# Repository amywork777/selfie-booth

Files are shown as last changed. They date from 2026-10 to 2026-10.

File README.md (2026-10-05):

# Selfie booth

An iPad selfie booth that prints on a 4x6 thermal label printer. Guests pick how many photos, pick a
pattern, add a caption (or a doodle), pose, and walk away with a print.

**Not technical? Read [START HERE](START%20HERE.md)** and double-click `Start Booth` on a Mac.

```
iPad (Safari) ··Wi-Fi··> a Mac or Raspberry Pi running server.py ──USB──> thermal printer
```

The iPad can't drive a USB printer itself, so a small computer sits in the middle. The iPad page does
everything people see: camera, countdown, patterns, caption, and turning the photo into printer dots.
The server only passes the finished label to the printer over USB. No printer driver is needed.

## What you need

- An iPad (any recent one with a front camera) on the same Wi-Fi as the computer.
- A Mac (or a Raspberry Pi, see below).
- A 4x6 direct thermal label printer that understands **TSPL** commands. Built and tested with a
  **Rollo X1038** (the USB model). Other TSPL printers should work after changing the USB IDs (below).
- 4x6 direct thermal labels.

## Run it on a Mac

Double-click **Start Booth** (`Start Booth.command`). The first run makes a Python environment and
installs `requirements.txt` (pyusb, Pillow, and libusb-package, which bundles libusb so no Homebrew is
needed), and it keeps the Mac awake while the booth runs. By hand, the same thing is:

```
python3 -m venv .venv && .venv/bin/python -m pip install -r requirements.txt
caffeinate -i .venv/bin/python server.py
```

Every time:

1. Plug the printer into the Mac and switch it on.
2. Double-click **Start Booth** and leave its window open.
3. On the iPad (same Wi-Fi as the Mac), open **https://selfie-booth.local:8443**. Add it to the Home
   Screen (Share, Add to Home Screen) for one-tap opening, and turn on Guided Access (Settings,
   Accessibility) to lock the iPad to the booth.

The address is the same on any Wi-Fi: the server announces `selfie-booth.local` on whatever network
it's on.

### First time on an iPad: trust the booth (once)

The booth uses https because Safari only allows the live camera on https. The server makes its own
small certificate authority (kept in `certs/`, never committed). Each iPad trusts it once:

1. On the iPad, open **http://selfie-booth.local:8000** and tap **Download the booth certificate**, then
   Allow.
2. Settings, **Profile Downloaded**, Install.
3. Settings, General, About, **Certificate Trust Settings**, turn on **Selfie Booth**.

After that the booth opens with no warning, even after the Mac changes networks. If you delete the
`certs/` folder, a new authority is made and iPads need to do this again.

If `selfie-booth.local` doesn't load, the server also prints the Mac's own `.local` name and its IP
address to try instead. Also check the Mac didn't pop up an "allow incoming connections" box for Python.

## Using the booth

Guests go through:

1. **How many photos:** 1 photo, 2 poses, 2 x 2, or twin strips (4 poses printed twice, with a cut line).
2. **Pick a pattern:** Plain, Hearts, Polka dot, Gingham, Doodle, Daisy chain.
3. **Caption:** type a caption. On Plain they can also doodle on the label with a finger.
4. **Smile:** a 3-2-1 countdown per pose, then it prints on its own.

**Settings** (small button, top right, on steps 1 and 2) is for the host:

- **Captions:** *Guests write their own*, or *Same for everyone* with one event caption. With the same
  caption for everyone, guests skip step 3 (except on Plain, where it becomes "Doodle on it").
- **Date** on or off, **Sound** on or off.

To see every pattern and photo count at once: https://selfie-booth.local:8443/frames.html

## Files

| File | Does |
| --- | --- |
| `server.py` | Serves the iPad page over https, `POST /print` (PNG in, prints it), `GET /status`, `POST /log` |
| `printer.py` | Finds the printer over USB and wraps an image in TSPL (808 x 1218 dots, 1-bit) |
| `static/app.js` | The booth: steps, camera, countdown, doodling, printing |
| `static/label.js` | Draws the label: photo counts, patterns, stickers, caption |
| `static/dots.js` | Contrast and Floyd-Steinberg dithering (tested: `npm test`) |
| `static/frames.html` | Every pattern and count side by side |
| `print_photo.py` | Print any photo from Terminal: `.venv/bin/python print_photo.py photo.jpg` |

## A different printer

In `printer.py`:

- `VID, PID`: your printer's USB IDs. On a Mac, find them with `system_profiler SPUSBDataType`.
- `PAPERS`: the paper sizes the booth offers (also in `static/label.js`). Labels use a gap, continuous rolls don't.
- `INVERT`: flip it if prints come out as a negative.
- Label widths are rounded down to a multiple of 8 dots (4 in is 808, not 812), or every row skews.

## Run it on a Raspberry Pi instead of a Mac (not tested yet)

Needs a Raspberry Pi Zero 2 W, a microSD card (8 GB+), a micro-USB OTG adapter for the printer cable,
and a micro-USB power supply.

1. Flash the card with Raspberry Pi Imager: Raspberry Pi OS Lite (64-bit). In its settings set a
   hostname (e.g. `booth`), your Wi-Fi, and turn on SSH.
2. Printer cable into the OTG adapter, into the Pi's port labelled **USB** (the middle one). Power into
   **PWR IN** (the corner one).
3. Copy the folder over (without `.venv` and `certs`), then on the Pi:
   `sudo apt install -y python3-venv libusb-1.0-0 openssl`, the same venv and `requirements.txt` install,
   and `sudo .venv/bin/python server.py` (raw USB needs permission).
4. On the iPad, open https://selfie-booth.local:8443 as before (the Pi announces the same name through
   Avahi, if `avahi-utils` is installed). The Pi makes its own certificate authority, so each iPad trusts it
   once, from http://selfie-booth.local:8000.

Still to do for the Pi: a udev rule so it doesn't need `sudo`, starting on boot, and having the Pi make
its own Wi-Fi so the booth works at venues without Wi-Fi.

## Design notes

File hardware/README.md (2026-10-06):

# Booth hardware

Two designs:

- **Laser-cut box** (for conventions and anywhere things might walk off): everything inside a
  plywood box, with only the screen and the print slot showing. See below.
- **3D-printed stand** (for home and parties): the iPad on top of the printer. Further down.

## Laser-cut box

Nine pieces of 1/4 in (6.35 mm) MDF or plywood, **no screws or hardware**: just wood glue for the box itself.
393 x 270 x 265 mm, finger-jointed, and every piece cuts on a Glowforge in one go.

Inside: a 14 in MacBook Pro lies closed in a bay across the bottom. A deck over it carries the iPad
mini on the left (standing on the deck, pressed against the front window by one holder plate) and
the Rollo on the right behind the print slot, with its labels behind it. Cut only: nothing is engraved.

The back is removable: two tabs on its bottom edge drop into slots in the floor, and a **lock bar**
slides through both side walls just behind it. Pull the bar out by its heart handle, tip the back
out, and the MacBook slides out the back.

**Cut files** (`DXF/box/`, all on the `CUT` layer), one of each:

| Part | What it does |
| --- | --- |
| front | iPad window (94% of the iPad face shows, camera included) and print slot |
| left, right | finger joints, slots for the deck's tabs and the lock bar |
| top, bottom | finger joints; the bottom has slots for the back's tabs |
| deck | over the MacBook; notch for the iPad's cable, hole for the printer's cable, slots for the holder |
| ipad_holder | presses the iPad against the window; tabs into the deck |
| back | drops into the floor slots; cord notch, a row of vent slots behind the MacBook |
| lock_bar | slides through the side walls to hold the back on; heart handle |

**Also needed:** wood glue; a straight USB-C cable for the iPad (it plugs down through the deck); a
USB-C to USB-A adapter for the printer cable; an HDMI dummy plug for the MacBook (see below).

**Assembly:**

1. Glue the box: front, bottom, sides, the deck (tabs through the sides), then the top.
2. Plug the iPad's cable into it from below through the deck notch, stand the iPad on the deck face
   against the window, and press the holder plate's tabs into the deck behind it.
3. Printer on the deck, pushed to the front; labels behind it feeding in. Cables down through the
   deck to the MacBook.
4. Slide the MacBook (lid closed, dummy plug in, charger connected) into the bay from the back.
5. Drop the back's tabs into the floor slots, tip it upright, and slide the lock bar through the side
   walls behind it until the heart handle stops it.

**Keeping the MacBook awake with its lid closed:** a closed MacBook sleeps unless it's in Apple's
"clamshell mode", which needs its charger connected and a display attached. Plug an **HDMI dummy
plug** (about $8, "4K HDMI headless display emulator") into its HDMI port and keep the charger in.
Do the one-time "Start Automatically" setup from START HERE with the lid open, then close it.

**For any thickness of wood:** https://amywork777.github.io/selfie-booth/box.html redraws the cut files
live for the thickness you type, shows the sheets, downloads them as a ZIP (Glowforge SVGs and DXFs) and shows
the box in 3D. It rebuilds the pieces in JavaScript (`docs/box/box.js`), a port of `src/box.py`. After changing the
box, check the port still matches: `.venv/bin/python src/box_web.py reference 5.5 6.35 7 && node checks/box_web_check.mjs 5.5 6.35 7`.

**Before cutting:** measure the printer (published size: 195 x 75 x 85 mm). The print slot is 130 x
60 mm and covers the whole upper part of the printer's front, so the label gets out wherever it leaves
the printer. Measure your sheet and cut one test joint first: real 1/4 in sheets are often a little thinner
than 6.35 mm (use the web page above, or change `T` in `src/box_dims.py` and rebuild).

**Ordering from SendCutSend instead:** upload the nine files in `DXF/box_sendcutsend/` (one of each),
material Baltic Birch Plywood, .250 in. They're built for that sheet's 6.35 mm. Remake them with
`.venv/bin/python src/box_sendcutsend.py`. Quoted 2026-10-05 at $268.59 for one box (free shipping); 1/4 in
MDF came out slightly dearer than the plywood, and 1/8 in hardboard is about half price but too thin for this design.

Rebuild and check: `.venv/bin/python src/box.py && .venv/bin/python src/box_parts.py && .venv/bin/python checks/box_check.py`

## 3D-printed stand

A 3D-printed stand that puts the iPad mini on top of the Rollo X1038, plus two laser-cut panels:
a scalloped bezel with a "selfie booth" sign around the iPad, and a front plate over the printer
with a slot where the print comes out.

Everything can be 3D printed. If you have a laser cutter, the two panels can be cut instead.

| Part | 3D print | Or laser cut |
| --- | --- | --- |
| Saddle (legs + deck over the printer) | `3MF/saddle_print.3mf`: print as loaded, deck down. No supports. | |
| Cradle (holds the iPad, tilted back 15°) | `3MF/cradle_print.3mf`: print standing on its base. No supports. | |
| Bezel and sign (170 x 247 mm) | `3MF/bezel_print.3mf`: flat, lettering up. | `DXF/bezel.dxf`, 3 mm sheet |
| Front plate (245 x 103 mm) | `3MF/front_plate_print.3mf`: flat, lettering up. | `DXF/front_plate.dxf`, 3 mm sheet |
| Sign topper (event name, above the iPad) | `3MF/sign_topper_print.3mf`: flat, lettering up. Posts slide into the sleeves on the back of the cradle. | |
| Table sign (the four steps) | `3MF/table_sign_print.3mf`: flat, lettering up. | |
| Table sign base | `3MF/table_sign_base_print.3mf`: as loaded. | |
| Screws | 4 x M3 x 12 self-tapping, or glue | |

Every part fits a 256 mm Bambu plate. Together they are about 260 cm³ of solid model. To use even less
filament, slice with 2 walls and 10% infill (the parts are mostly thin walls, so infill barely matters).
The printed panels are 2 mm thick with the lettering raised 0.8 mm: for two colours, add a filament
change at the layer just above 2 mm in Bambu Studio. In the DXFs, the `CUT` layer cuts and `ENGRAVE` engraves.

## Putting it together

1. Screw the cradle onto the deck (4 screws from underneath), or glue it.
2. Set the saddle over the printer. Cables go out the open back.
3. Hang the front plate on the four pegs on the front of the legs: push the big round holes over the
   peg heads, then let the plate drop so it stands on the table.
4. Put the iPad in the cradle, then hang the bezel on the four pegs on the cradle's side walls the
   same way.
5. To load labels, lift the whole stand off the printer.

## Signs

The topper's text is `SIGN_TEXT` in `src/dims.py` ("amy's 30th" for now). Change it for each event and
run `.venv/bin/python src/signs.py` to make a new `sign_topper_print.3mf`. The topper sits behind the
camera, so it never shows up in photos.

## Dimensions and assumptions

All sizes live in `src/dims.py`. Change a number there and rerun the scripts to regenerate everything.

- **Printer:** 195 W x 75 D x 85 H mm, from published specs for the Rollo X1038. The stand only
  depends on width and height (3 mm clearance each side, 6 mm above), so the depth and the exact
  label exit don't affect the fit. **Measure your printer before printing**: if it is wider or taller,
  change `PRINTER_W` / `PRINTER_H`.
- **iPad:** iPad mini 6 / 7, 195.4 x 134.8 x 6.3 mm, portrait. The cradle has a notch for a
  right-angle USB-C cable.
- **Label exit:** not published. The deck starts 25 mm behind the printer's front edge and the front
  plate's slot runs from 24 mm below the printer top to 4 mm above it, so a label can leave through
  the front or over the top-front edge.
- **Panels:** laser cut from 3 mm sheet (`PANEL_T`, the pegs follow it), or printed 2 mm thick
  (`PRINT_PANEL_T`).

## Rebuilding

```
cd hardware
uv venv --python 3.11 .venv && uv pip install --python .venv/bin/python "cadgen[snapshot]==0.7.9"
.venv/bin/python src/saddle.py
.venv/bin/python src/cradle.py
.venv/bin/python src/print_layout.py
.venv/bin/python src/bezel.py
.venv/bin/python src/front_plate.py
.venv/bin/python src/panels_print.py
.venv/bin/python src/signs.py
.venv/bin/python src/booth.py      # everything together, with stand-in printer and iPad, for review
.venv/bin/python checks/fit_check.py
```

`checks/fit_check.py` confirms every printed part is one connected piece and fits the plate, the
cradle's ribs are joined to solid back plate, no parts collide, the saddle stays at least 3 mm from the
printer, the pegs line up with the keyholes, the screw holes line up, and the topper sits in its
sleeves. Run it after changing anything.

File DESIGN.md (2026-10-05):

Route: taste/routes/toy.md. Tokens: taste/kit/tokens/toy.css (copied to static/tokens.css).
Toy page, Experience mode. Butter stage, plum outlines, candy pink accent, dot-matrix title, springy outlined controls.
Sound on after first gesture, with a Sound toggle. Reduced motion snaps to end states (no pop, no flash).
Signature moment: the live mirror is drawn as the printer's own dots, so the screen shows exactly what will print.
Hand-made detail: the Doodle pattern and finger doodling on Plain. (The "Free prints" sticker was removed at Amy's request.)
Fonts: Doto (title, labels, printed date), Caveat (printed caption), bundled in static/fonts so the Pi works offline.
Print art: bold black shapes and solid fills only; thin lines and greys print badly on thermal paper.
Precedence: this file > taste/SIGNATURE.md > Impeccable defaults.

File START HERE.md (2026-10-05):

# Selfie booth: start here

You need a Mac, an iPad, the Rollo printer (plugged into the Mac and switched on) and 4x6 labels.
The Mac and iPad must be on the same Wi-Fi.

## The first time (about 10 minutes)

### On the Mac

1. On this page, click the green **Code** button, then **Download ZIP**.
2. Open your Downloads folder and double-click the ZIP. You get a folder called `selfie-booth`.
   Move it somewhere you'll find it, like your Desktop.
3. In that folder, double-click **Start Booth**.
   - If the Mac says it can't open it because it's from the internet: open **System Settings**,
     go to **Privacy & Security**, scroll down, and click **Open Anyway** next to Start Booth. Then
     double-click Start Booth again.
   - If a box asks to install **developer tools**: click **Install**, wait until it finishes (a few
     minutes), then double-click Start Booth again.
4. A window opens and sets things up for a minute or two. When it says **Selfie booth ready**, it's
   running. Leave that window open.

### On the iPad (once per iPad)

1. When the booth starts, the Mac shows a page with a big QR code. Point the iPad camera at it and tap
   the link that pops up.
2. Tap **Download the booth certificate**, then **Allow**.
3. Open **Settings**. Tap **Profile Downloaded** near the top, then **Install** (enter the iPad
   passcode if asked).
4. In Settings, go to **General**, **About**, **Certificate Trust Settings**, and turn on
   **Selfie Booth**.
5. Scan the QR code again (or go back to Safari and tap **Open the booth**). Allow the camera.
6. Tap the Share button, then **Add to Home Screen**.

## Every time after that

1. Plug the printer into the Mac and switch it on.
2. Double-click **Start Booth** on the Mac. Leave the window open.
3. On the iPad, tap the **Selfie booth** icon on the Home Screen (or scan the QR code on the Mac).

To stop the booth, close the Start Booth window on the Mac.

## Mac mini with no screen

Do this once at home with a screen, keyboard and mouse plugged into the Mac mini (any TV with HDMI works):

1. Do "The first time" steps above.
2. On the Mac mini, join your **phone's hotspot** once (Wi-Fi menu, top right of the screen). It will rejoin it
   by itself at any event. Or plug the Mac mini into the router with an Ethernet cable.
3. In the selfie-booth folder, double-click **Start Automatically**.
4. Open **System Settings**, **Users & Groups**, and set **Automatically log in** to your account.
   - Greyed out? That means FileVault is on. Then at events: switch the Mac mini on, wait a minute, type your
     password and press Return. No screen needed.

At the event:

1. Turn on your phone's hotspot. Join the iPad to it too.
2. Plug in the printer and switch on the Mac mini.
3. Wait about a minute, then tap the booth icon on the iPad.
   - If it can't find the booth, open **http://selfie-booth.local:8000** in Safari.

To turn automatic start off, double-click **Stop Starting Automatically**.

The 2024 Mac mini only has USB-C ports: use a USB-C to USB-A adapter for the printer cable.

## Before guests arrive

The booth starts on a keypad: guests need a code to start (staff type it in when someone has paid).
The code is **0000** to begin with. Each code gets one session: pick, pose, print. Then it locks again.
It also locks again if someone walks away for a minute.

On the iPad, tap **Settings** in the top corner of the booth (it asks for the code too):

- **Code to start:** "Guests need a code" or "Free for all", and change the 4-digit code.

- **Captions:** let each guest write their own, or pick **Same for everyone** and type the event
  name (like "amy's 30th").
- **Paper:** pick what's loaded in the printer: 4 x 6 labels (the usual), a 4 x 6 continuous roll, or
  4 x 4, 4 x 3, 4 x 2 or 3 x 2 labels. The small 4 x 2 and 3 x 2 labels fit one photo, so guests skip
  the "how many photos" step.
- Turn the date and sound on or off.

Tip: turn on **Guided Access** (iPad Settings, Accessibility) so guests can't leave the booth.

## If something's wrong

- **The iPad can't find selfie-booth.local:** check the Mac and iPad are on the same Wi-Fi and the
  Start Booth window is still open. The window also shows another address to try.
- **"Printer not found"** (on the Mac's QR page or in the booth): check the printer is plugged in and
  switched on.
- **The Mac asks to allow incoming connections:** click **Allow**.
- **Nothing prints:** check the labels are loaded, then close Start Booth and open it again.

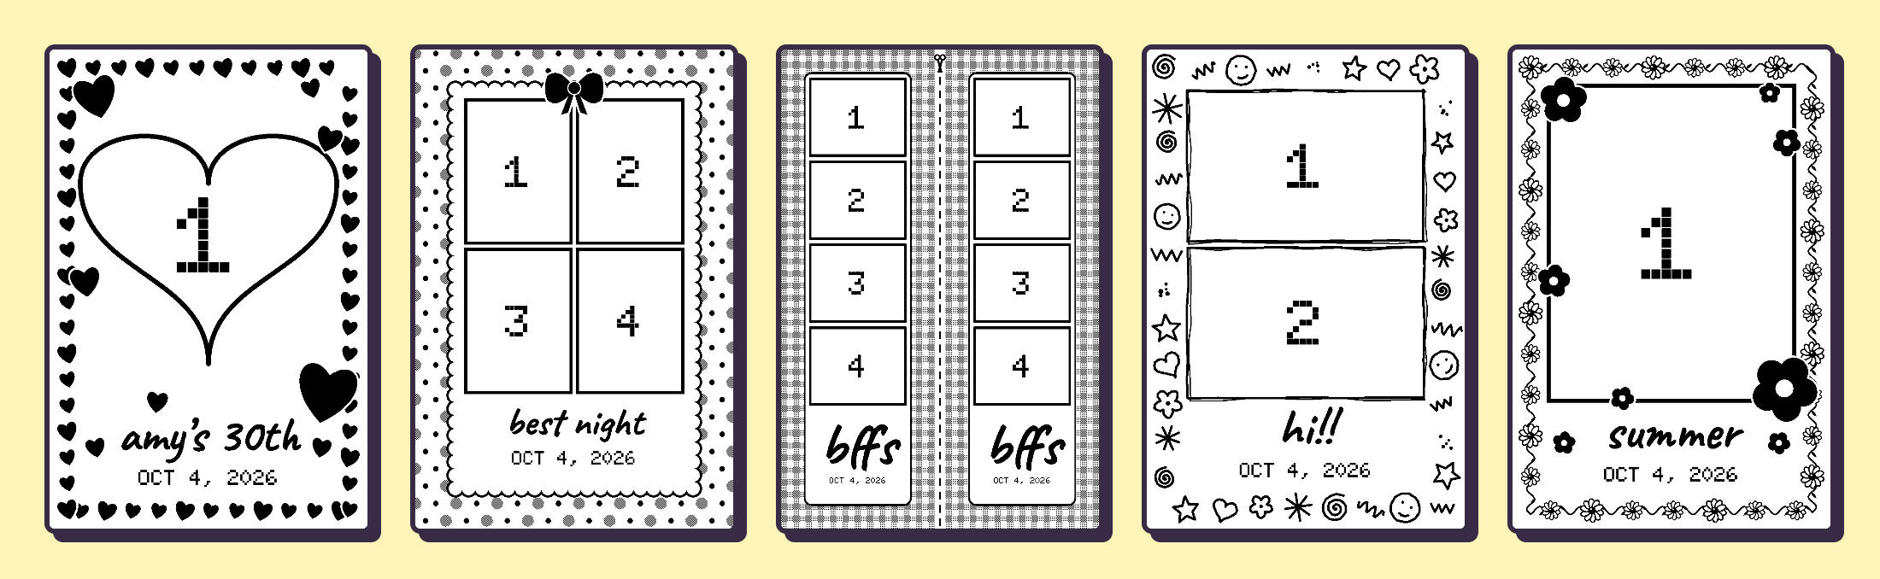
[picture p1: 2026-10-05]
docs/designs.png

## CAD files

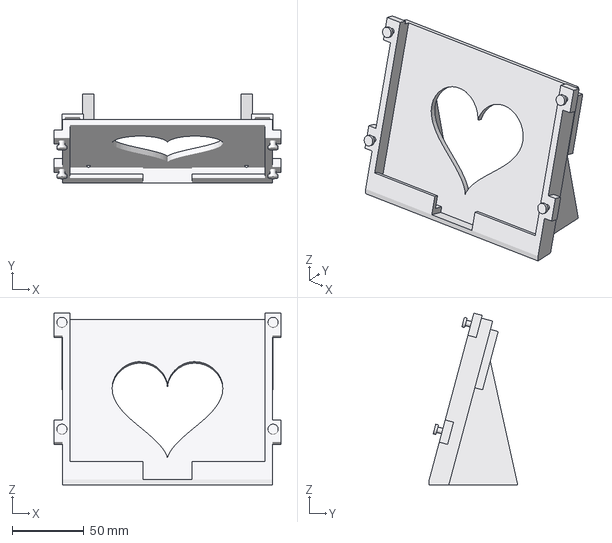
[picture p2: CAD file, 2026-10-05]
hardware/3MF/cradle_print.3mf
158.0 x 61.6 x 119.6 mm

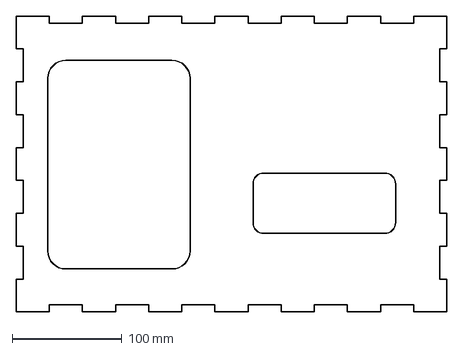
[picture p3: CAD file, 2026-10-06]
hardware/DXF/box/front.dxf
393.0 x 270.0 mm

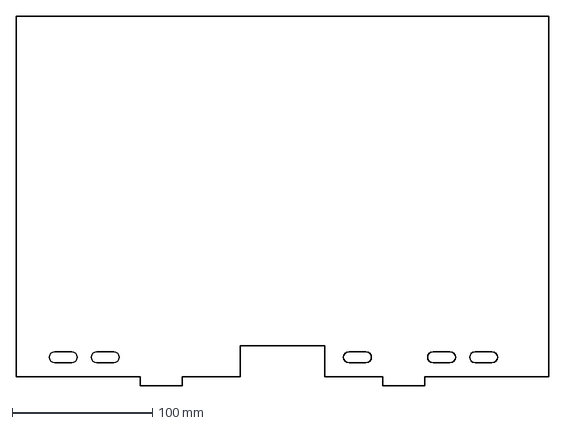
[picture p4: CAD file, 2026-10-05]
hardware/DXF/box_sendcutsend/back.dxf
380.3 x 263.6 mm

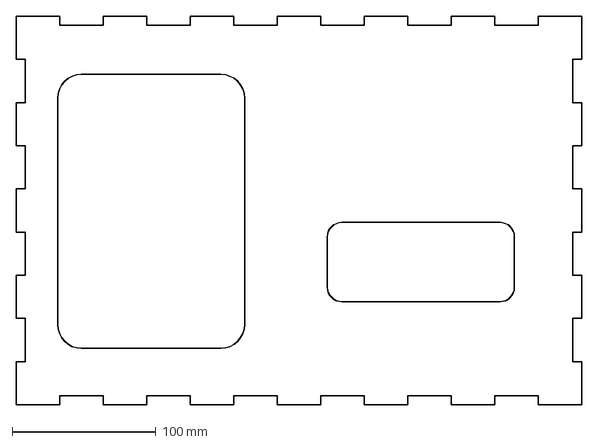
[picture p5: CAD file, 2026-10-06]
hardware/DXF/box_sheets/sheet1_front.dxf
393.0 x 270.0 mm

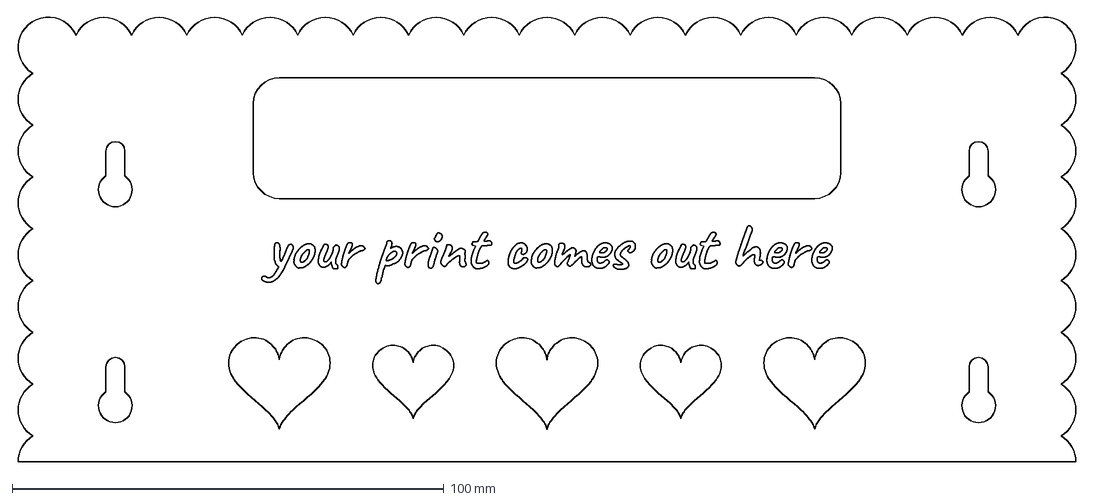
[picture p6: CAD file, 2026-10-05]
hardware/DXF/front_plate.dxf
246.0 x 103.3 mm

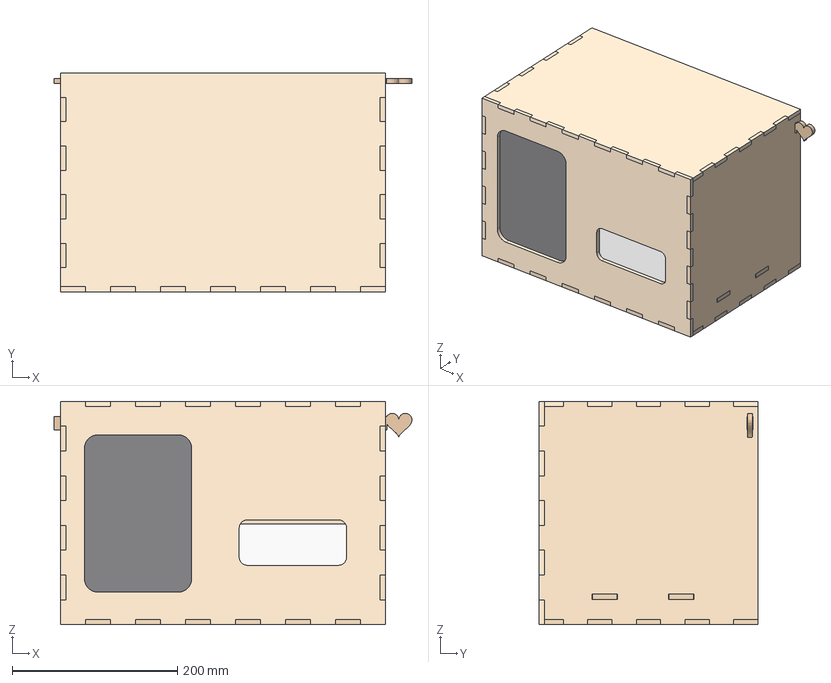
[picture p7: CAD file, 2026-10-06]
hardware/STEP/box.step
433.3 x 265.0 x 270.0 mm
front
left
right
bottom
top
deck
ipad_holder
back
lock_bar
rollo_standin
labels_standin
macbook_standin
ipad_standin

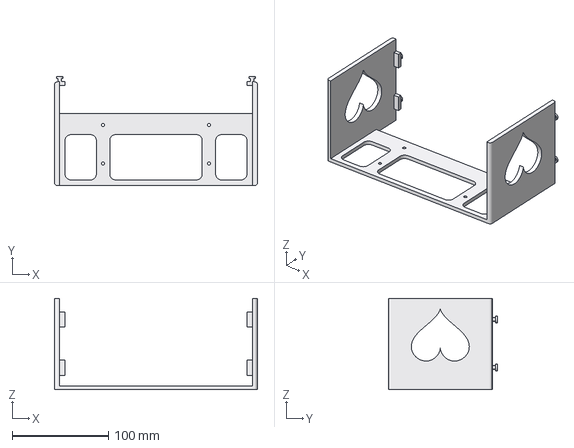
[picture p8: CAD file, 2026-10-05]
hardware/3MF/saddle_print.3mf
211.0 x 113.6 x 95.0 mm

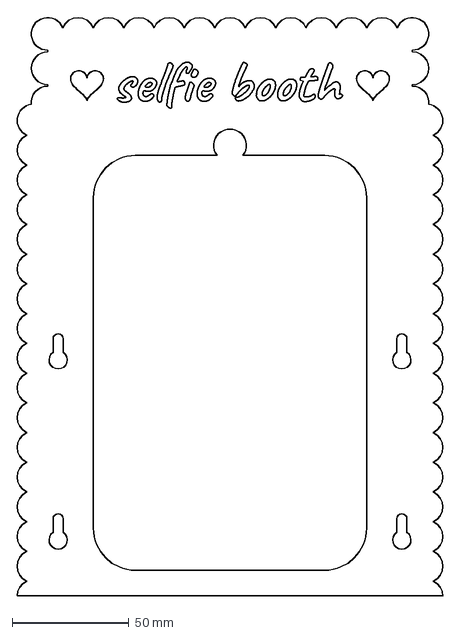
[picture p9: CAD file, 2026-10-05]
hardware/DXF/bezel.dxf
182.8 x 248.1 mm

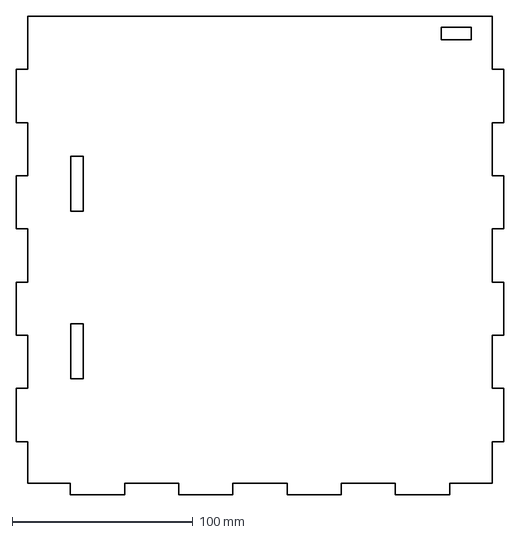
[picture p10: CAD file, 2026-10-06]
hardware/DXF/box/right.dxf
270.0 x 265.0 mm

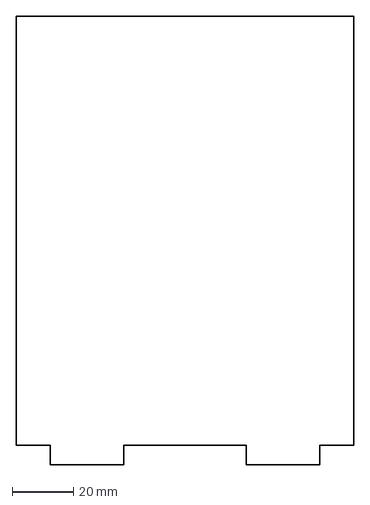
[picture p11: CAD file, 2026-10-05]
hardware/DXF/box_sendcutsend/ipad_holder.dxf
110.0 x 146.3 mm

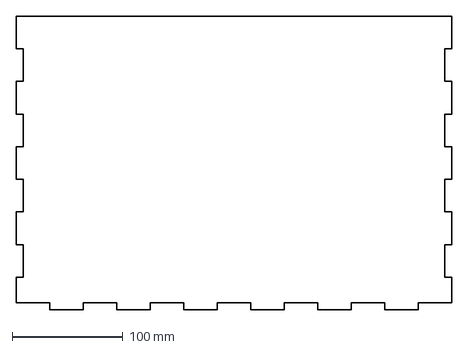
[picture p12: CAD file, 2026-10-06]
hardware/DXF/box_sheets/sheet3_top.dxf
393.0 x 265.0 mm

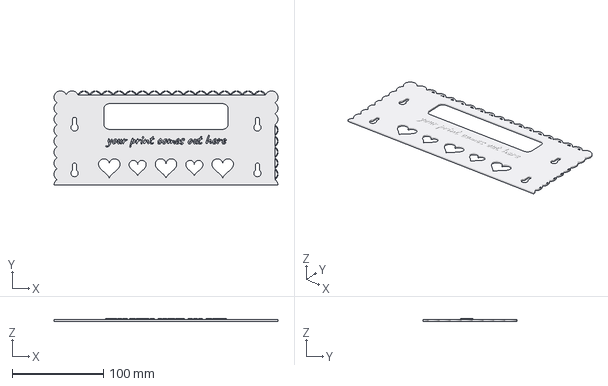
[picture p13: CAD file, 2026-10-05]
hardware/3MF/front_plate_print.3mf
245.0 x 103.0 x 2.80 mm

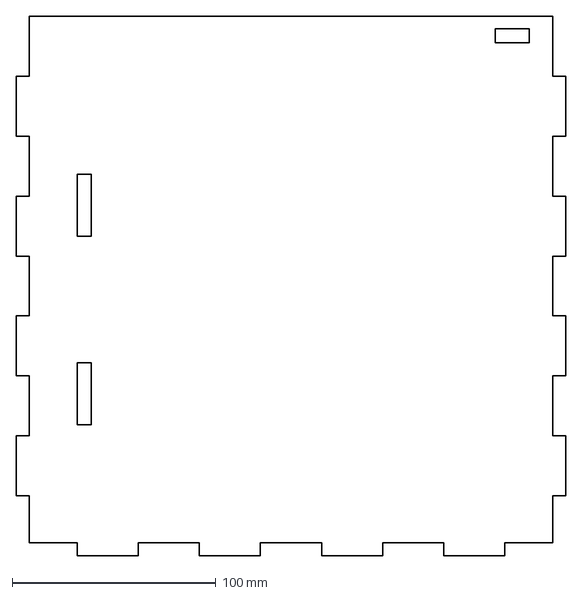
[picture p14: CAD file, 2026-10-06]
hardware/DXF/box/left.dxf
270.0 x 265.0 mm

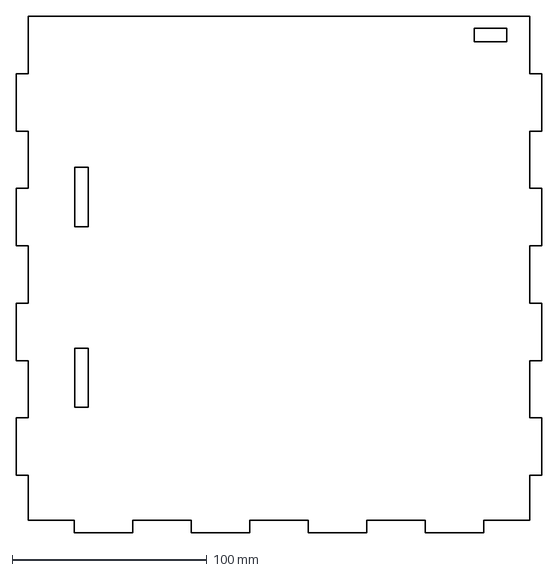
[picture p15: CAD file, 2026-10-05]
hardware/DXF/box_sendcutsend/left.dxf
270.0 x 265.0 mm

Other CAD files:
hardware/STEP/saddle.step
hardware/DXF/box_sheets/sheet2_back.dxf
hardware/STEP/cradle.step
hardware/3MF/sign_topper_print.3mf
hardware/3MF/bezel_print.3mf
hardware/3MF/table_sign_base_print.3mf
hardware/3MF/table_sign_print.3mf
hardware/DXF/box/back.dxf
hardware/DXF/box/bottom.dxf
hardware/DXF/box/deck.dxf
hardware/DXF/box/ipad_holder.dxf
hardware/DXF/box/ipad_pocket.dxf
hardware/DXF/box/lock_bar.dxf
hardware/DXF/box/post_layer.dxf
hardware/DXF/box/shelf.dxf
hardware/DXF/box/top.dxf
hardware/DXF/box/top_sign.dxf
hardware/DXF/box_sendcutsend/bottom.dxf
hardware/DXF/box_sendcutsend/deck.dxf
hardware/DXF/box_sendcutsend/front.dxf
hardware/DXF/box_sendcutsend/lock_bar.dxf
hardware/DXF/box_sendcutsend/right.dxf
hardware/DXF/box_sendcutsend/top.dxf
hardware/DXF/box_sheets/sheet4_bottom.dxf
hardware/DXF/box_sheets/sheet5_left_and_ipad_holder.dxf
hardware/DXF/box_sheets/sheet6_right.dxf
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

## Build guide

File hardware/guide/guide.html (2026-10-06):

# Selfie booth box

A laser-cut wooden box that holds the whole selfie booth: a 14 in MacBook Pro hidden in the base, an iPad mini behind a window in the front, and a Rollo label printer behind a print slot. Nine pieces of 1/4 in MDF or plywood, no screws, just wood glue. Finished size 393 x 270 x 265 mm (15.5 x 10.6 x 10.4 in).

## Cut files

All nine pieces come laid out on seven 12 x 20 in sheets of 1/4 in (6.35 mm) MDF, ready to cut. Each sheet comes two ways: an SVG for the Glowforge app and a DXF for other lasers. Every line is a cut, holes included. Nothing is engraved.

Sheet | Pieces
1 | front
2 | back
3 | top
4 | bottom
5 | left side and iPad holder
6 | right side
7 | deck and lock bar



frontiPad window and print slot. 393 x 270



backRemovable. Tabs, cord notch, vent slots. 381 x 264



leftSlots for the deck and lock bar. 270 x 265



rightSame as the left. 270 x 265



top393 x 265



bottomSlots for the back's tabs. 393 x 265



deckSits over the MacBook. Cable notch and hole, holder slots. 393 x 241



ipad_holderHolds the iPad against the window. 146 x 110



lock_barHolds the back on; heart handle. 433 x 29

## Also needed

Item | Why
Wood glue | For the box. The back, holder and lock bar are not glued so they can come out.
Straight USB-C cable | Charges the iPad; plugs in from below through the deck.
USB-C to USB-A adapter | The printer's cable is USB-A; the MacBook has USB-C.
HDMI dummy plug ("4K HDMI headless display emulator", about $8) | Lets the MacBook keep running with its lid closed.
Fine sandpaper | For any tab that's too tight.

Before cutting everything: measure your wood. "1/4 in" sheets are often a little thinner than 6.35 mm, and the finger joints fit best when the files match. Type your thickness at amywork777.github.io/selfie-booth/box.html and it makes the files for it.

## Assembly



1

Glue the front, both sides and the bottom. The finger joints only go together one way. The slot near the top back of each side is for the lock bar.



2

Slide in the deck. Its four tabs go through the matching slots in the sides. The notch in its front edge goes on the left, behind the iPad window. Glue the tabs.



3

Glue on the top and let everything dry. The back stays off.



4

Put in the iPad. From underneath, push the USB-C cable up through the deck notch and plug it into the iPad. Stand the iPad on the deck, screen against the window, camera at the top. Press the holder plate's two tabs into the slots behind it. If the tabs are loose, a dot of glue holds them; tight, sand them a little.



5

MacBook, printer and labels. Plug the HDMI dummy plug and charger into the MacBook, close the lid, and slide it into the bay under the deck from the back. Set the printer on the deck, pushed right up to the front so its label lines up with the slot. Put the stack of 4 x 6 labels behind it and feed the first label into the printer's back slot. Run the printer cable and the iPad cable down through the deck to the MacBook.



6

Put on the back. Lead the power cords out through the notch at the bottom. Drop the back's two bottom tabs into the slots in the floor and tip it upright.



7

Slide in the lock bar. Facing the back of the box, push it in through the slot near the top of the left-hand wall, straight end first, through both walls behind the back panel, until the heart handle stops against the wall (as in the picture). To open the box later, pull the bar out by the heart.



8

Switch on. Plug in the power. The booth software, setup steps and the code to start are at amywork777.github.io/selfie-booth. Guests need a code to start (0000 to begin with; change it in Settings).

## Refilling labels

Slide out the lock bar, tip the back out, drop a new stack behind the printer and feed the first label in.

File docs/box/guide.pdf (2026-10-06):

# Selfie booth box

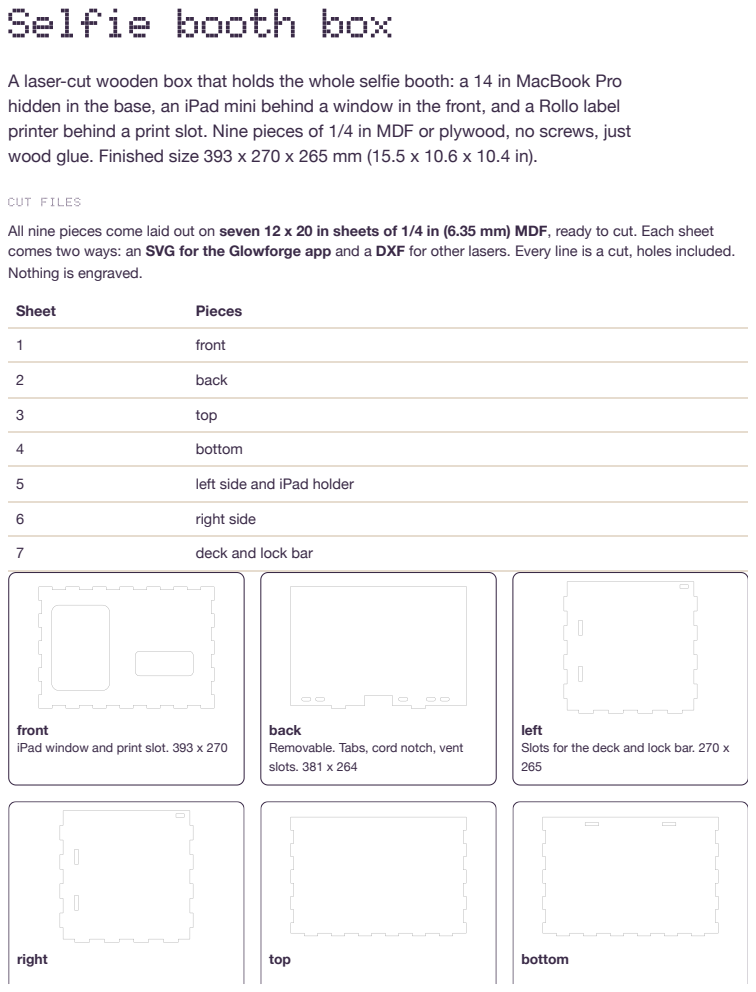
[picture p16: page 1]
Sheet; Pieces; front; back; top; bottom; left side and iPad holder; right side; deck and lock bar; right

A laser-cut wooden box that holds the whole selfie booth: a 14 in MacBook Pro
hidden in the base, an iPad mini behind a window in the front, and a Rollo label
printer behind a print slot. Nine pieces of 1/4 in MDF or plywood, no screws, just
wood glue. Finished size 393 x 270 x 265 mm (15.5 x 10.6 x 10.4 in).

CUT FILES
All nine pieces come laid out on seven 12 x 20 in sheets of 1/4 in (6.35 mm) MDF, ready to cut. Each sheet
comes two ways: an SVG for the Glowforge app and a DXF for other lasers. Every line is a cut, holes included.
Nothing is engraved.

front
iPad window and print slot. 393 x 270

back
Removable. Tabs, cord notch, vent
slots. 381 x 264

left
Slots for the deck and lock bar. 270 x

Same as the left. 270 x 265 | 393 x 265 | Slots for the back's tabs. 393 x 265

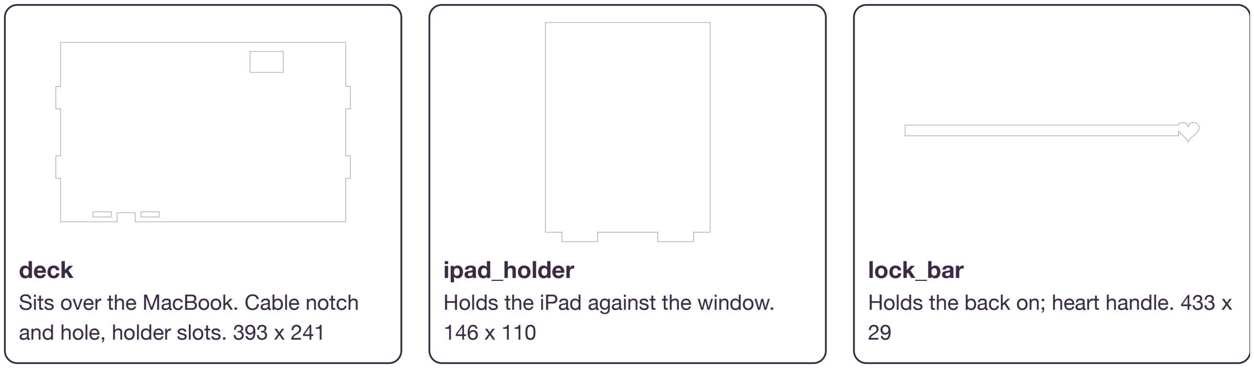
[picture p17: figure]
deck Sits over the MacBook. Cable notch and hole, holder slots. 393 x 241; ipad_holder Holds the iPad against the window. 146 x 110; lock_bar Holds the back on; heart handle. 433 x 29

ALSO NEEDED

Item | Why
Wood glue | For the box. The back, holder and lock bar are not glued so they can come out.
Straight USB-C cable | Charges the iPad; plugs in from below through the deck.
USB-C to USB-A adapter | The printer's cable is USB-A; the MacBook has USB-C.
HDMI dummy plug ("4K HDMI headless display emulator", about $8) | Lets the MacBook keep running with its lid closed.
Fine sandpaper | For any tab that's too tight.

Before cutting everything: measure your wood. "1/4 in" sheets are often a little thinner than 6.35 mm, and the finger joints fit best when the files match. Type your thickness at amywork777.github.io/selfie-booth/box.html and it makes the files for it.

ASSEMBLY

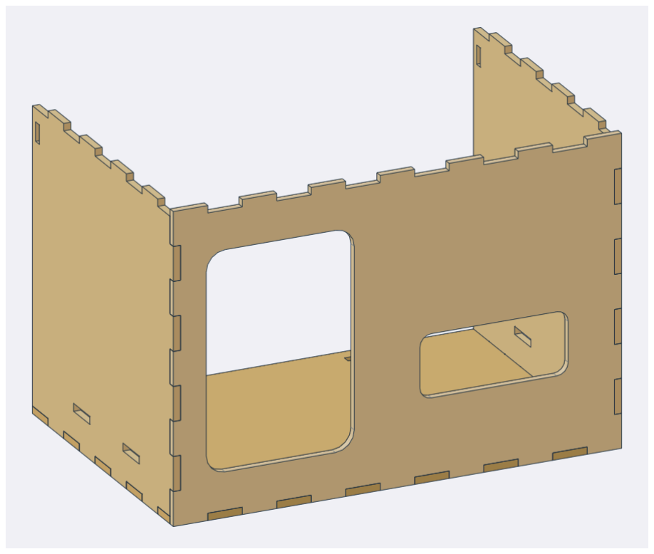
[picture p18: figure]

1

Glue the front, both sides and the bottom. The finger joints only go together one way. The slot near the top back of each side is for the lock bar.

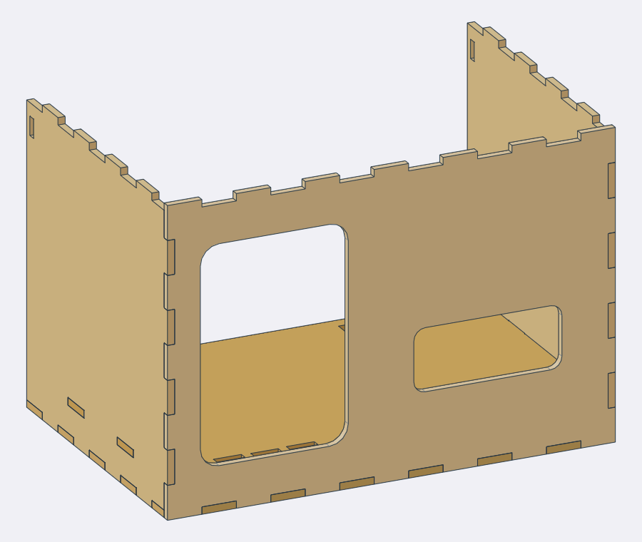
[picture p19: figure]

2

Slide in the deck. Its four tabs go through the matching slots in the sides. The notch in its front edge goes on the left, behind the iPad window. Glue the tabs.

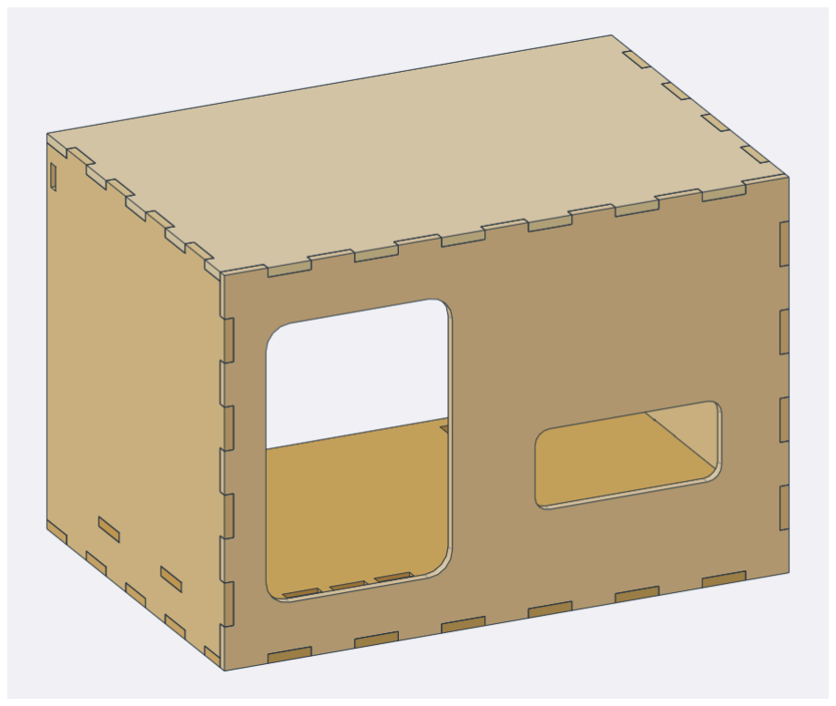
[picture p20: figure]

3

Glue on the top and let everything dry. The back stays off.

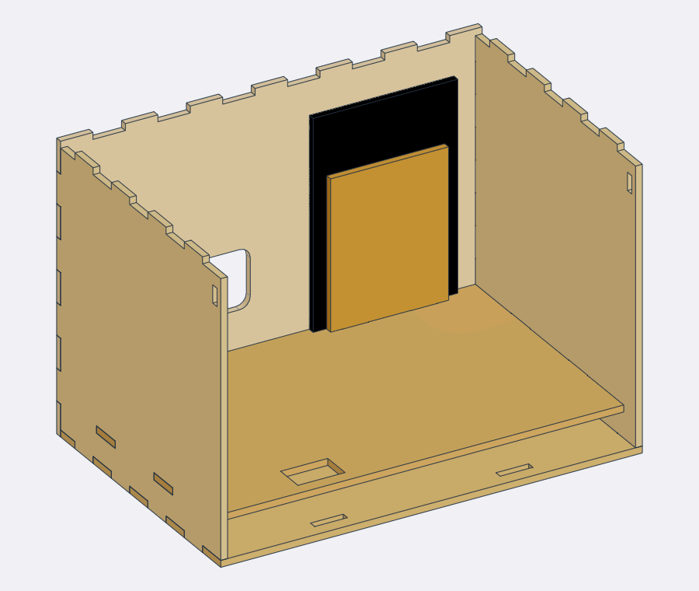
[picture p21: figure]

4

Put in the iPad. From underneath, push the USB-C cable up through the deck notch and plug it into the iPad. Stand the iPad on the deck, screen against the window, camera at the top. Press the holder plate's two tabs into the slots behind it. If the tabs are loose, a dot of glue holds them; tight, sand them a little.

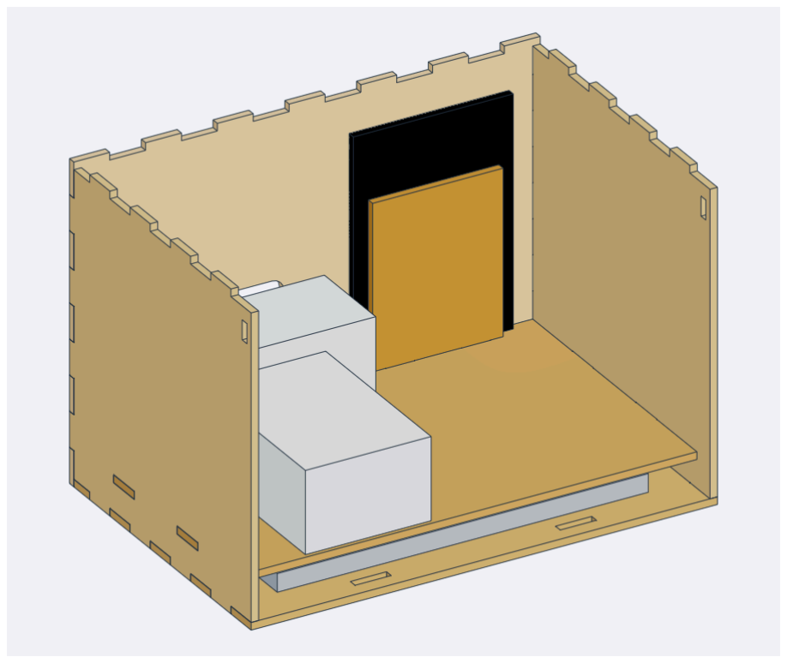
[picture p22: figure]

5

MacBook, printer and labels. Plug the HDMI dummy plug and charger into the MacBook, close the lid, and slide it into the bay under the deck from the back. Set the printer on the deck, pushed right up to the front so its label lines up with the slot. Put the stack of 4 x 6 labels behind it and feed the first label into the printer's back slot. Run the printer cable and the iPad cable down through the deck to the MacBook.

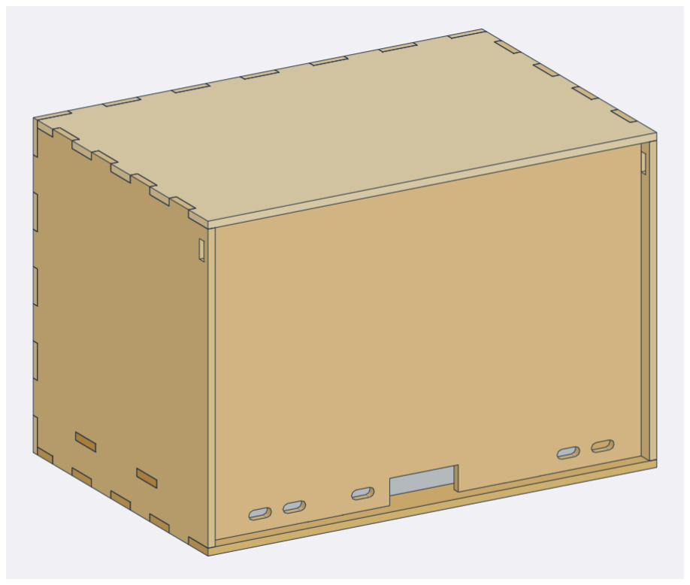
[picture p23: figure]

6

Put on the back. Lead the power cords out through the notch at the bottom. Drop the back's two bottom tabs into the slots in the floor and tip it upright.

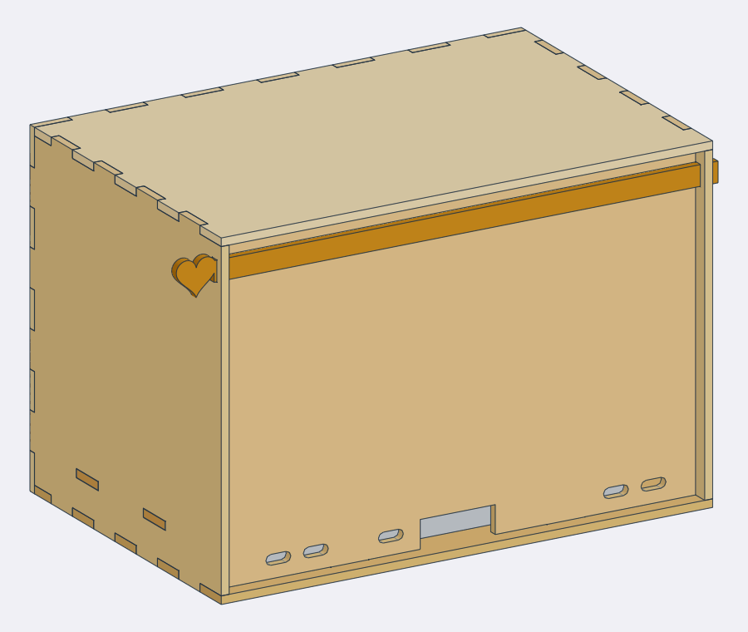
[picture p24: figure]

7

Slide in the lock bar. Facing the back of the box, push it in through the slot near the top of the left-hand wall, straight end first, through both walls behind the back panel, until the heart handle stops against the wall (as in the picture). To open the box later, pull the bar out by the heart.

8

Switch on. Plug in the power. The booth software, setup steps and the code to start are at amywork777.github.io/selfie-booth. Guests need a code to start (0000 to begin with; change it in Settings).

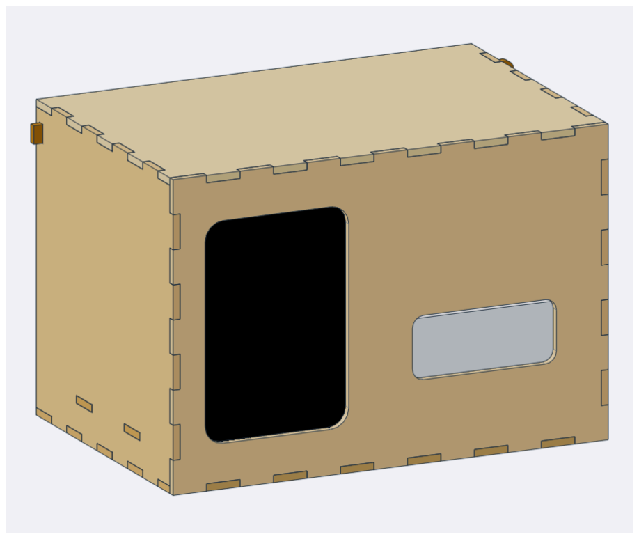
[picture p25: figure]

REFILLING LABELS
Slide out the lock bar, tip the back out, drop a new stack behind the printer and feed the first label in.

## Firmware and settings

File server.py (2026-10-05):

"""Selfie booth server: serves the iPad page and prints what it sends.

    .venv/bin/python server.py

The booth runs on https (Safari needs it for live camera), using a certificate
from a small certificate authority this server makes for itself. Each iPad
trusts that authority once, from the setup page on plain http, and then the
booth opens with no warning on any network, at https://<this computer>.local:8443.
"""

import io
import json
import mimetypes
import socket
import ssl
import subprocess
import sys
import tempfile
import threading
from http.server import BaseHTTPRequestHandler, ThreadingHTTPServer
from pathlib import Path

from PIL import Image

from printer import Printer, PrinterNotFound, label

HTTP_PORT, HTTPS_PORT = 8000, 8443
ROOT = Path(__file__).parent
STATIC = ROOT / "static"
MAX_UPLOAD = 20 * 1024 * 1024
CERTS = ROOT / "certs"
CA_CERT, CA_KEY = CERTS / "booth-ca.crt", CERTS / "booth-ca.key"
BOOTH_NAME = "selfie-booth.local"  # announced on the network, so the address never changes

printer = Printer()


def lan_ip():
    s = socket.socket(socket.AF_INET, socket.SOCK_DGRAM)
    try:
        s.connect(("10.255.255.255", 1))  # no packets sent; just picks the Wi-Fi interface
        return s.getsockname()[0]
    except OSError:
        return "127.0.0.1"
    finally:
        s.close()


def local_name():
    """This computer's Bonjour name, which iPads on the same network can reach: e.g. booth.local."""
    if sys.platform == "darwin":
        name = subprocess.run(["scutil", "--get", "LocalHostName"], capture_output=True, text=True).stdout.strip()
    else:
        name = socket.gethostname().split(".")[0]
    return f"{name or 'localhost'}.local"


def announce(ip):
    """Announce selfie-booth.local on this network (Bonjour), pointing at this computer.

    Returns the process doing it, or None if this system can't, in which case the
    computer's own .local name still works.
    """
    if sys.platform == "darwin":
        cmd = ["dns-sd", "-P", "Selfie Booth", "_https._tcp", "local", str(HTTPS_PORT), BOOTH_NAME, ip]
    else:
        cmd = ["avahi-publish", "-a", "-R", BOOTH_NAME, ip]
    try:
        return subprocess.Popen(cmd, stdout=subprocess.DEVNULL, stderr=subprocess.DEVNULL)
    except FileNotFoundError:
        return None


def openssl(*args):
    subprocess.run(["openssl", *args], check=True, capture_output=True)


def certificate(names, ip):
    """A certificate for this name and IP, signed by the booth's own authority (made once, kept forever).

    The authority never changes, so an iPad that trusted it once keeps trusting new certificates when
    the IP changes on another network.
    """
    CERTS.mkdir(exist_ok=True)
    if not CA_CERT.exists():
        openssl("req", "-x509", "-new", "-nodes", "-newkey", "rsa:2048", "-days", "3650",
                "-keyout", str(CA_KEY), "-out", str(CA_CERT), "-subj", "/CN=Selfie Booth",
                "-addext", "basicConstraints=critical,CA:TRUE",
                "-addext", "keyUsage=critical,keyCertSign,cRLSign")
    cert, key = CERTS / f"{names[-1]}-{ip}.crt", CERTS / f"{names[-1]}-{ip}.key"
    if not cert.exists():
        with tempfile.TemporaryDirectory() as tmp:
            csr, ext = Path(tmp) / "req.csr", Path(tmp) / "ext.cnf"
            # iPadOS only accepts server certificates valid for 825 days or less, with these extensions.
            ext.write_text(
                f"subjectAltName={','.join(f'DNS:{n}' for n in names)},DNS:localhost,IP:{ip},IP:127.0.0.1\n"
                "extendedKeyUsage=serverAuth\nbasicConstraints=CA:FALSE\n"
                "keyUsage=critical,digitalSignature,keyEncipherment\n"
            )
            openssl("req", "-new", "-nodes", "-newkey", "rsa:2048", "-keyout", str(key),
                    "-out", str(csr), "-subj", f"/CN={names[0]}")
            openssl("x509", "-req", "-in", str(csr), "-CA", str(CA_CERT), "-CAkey", str(CA_KEY),
                    "-CAcreateserial", "-out", str(cert), "-days", "825", "-sha256", "-extfile", str(ext))
    return cert, key


class Booth(BaseHTTPRequestHandler):
    def log_message(self, fmt, *args):
        if "/status" not in self.path and "/log" not in self.path:
            super().log_message(fmt, *args)

    def reply(self, code, body=b"", kind="application/json"):
        self.send_response(code)
        self.send_header("Content-Type", kind)
        self.send_header("Content-Length", str(len(body)))
        self.send_header("Cache-Control", "no-store")
        # The http setup page probes /status to see whether this iPad already trusts the booth.
        self.send_header("Access-Control-Allow-Origin", "*")
        self.end_headers()
        self.wfile.write(body)

    def do_GET(self):
        if self.path == "/status":
            return self.reply(200, json.dumps({"printer": printer.connected()}).encode())
        name = "index.html" if self.path in ("/", "") else self.path.split("?")[0].lstrip("/")
        path = (STATIC / name).resolve()
        if not path.is_relative_to(STATIC.resolve()) or not path.is_file():
            return self.reply(404, b"not found", "text/plain")
        kind = mimetypes.guess_type(path.name)[0] or "application/octet-stream"
        if kind.startswith("text/") or kind.endswith("javascript"):
            kind += "; charset=utf-8"
        self.reply(200, path.read_bytes(), kind)

    def do_POST(self):
        if self.path == "/log":  # the iPad page reports its steps and errors here
            size = min(int(self.headers.get("Content-Length", 0)), 4096)
            print("ipad:", self.rfile.read(size).decode(errors="replace"))
            return self.reply(204)
        path, _, query = self.path.partition("?")
        if path != "/print":
            return self.reply(404)
        paper = dict(p.split("=", 1) for p in query.split("&") if "=" in p).get("paper", "4x6")
        size = int(self.headers.get("Content-Length", 0))
        if not 0 < size <= MAX_UPLOAD:
            return self.reply(413, b'{"error":"photo too large"}')
        try:
            img = Image.open(io.BytesIO(self.rfile.read(size)))
            # The page sends a finished, already dithered label: print it dot for dot.
            printer.send(label(img, dither=False, paper=paper))
            self.reply(200, b'{"ok":true}')
        except PrinterNotFound as e:
            self.reply(503, json.dumps({"error": str(e)}).encode())
        except Exception as e:
            print("print failed:", repr(e))
            self.reply(500, json.dumps({"error": "print failed"}).encode())


PAGE_STYLE = """
  body { margin: 0; padding: 40px 28px; background: #fff3b0; color: #3a2a47;
         font: 500 20px/1.4 "Helvetica Neue", Helvetica, Arial, sans-serif; }
  main { max-width: 620px; margin: 0 auto; }
  h1 { font-size: 40px; margin: 0 0 8px; }
  ol { padding-left: 24px; } li { margin: 12px 0; }
  a.btn { display: inline-block; margin: 8px 0 24px; padding: 20px 32px; border: 3px solid #3a2a47;
          border-radius: 22px; background: #ff6fa3; color: #3a2a47; font-weight: 700; text-decoration: none;
          box-shadow: 0 6px 0 #3a2a47; }
  a.ghost { background: #fff8d6; }
  code { font-size: 18px; }
  [hidden] { display: none !important; }
"""

# The iPad lands here from the QR code. If it already trusts the booth it goes straight in;
# otherwise it shows the one-time steps.
SETUP_PAGE = """<!doctype html>
<html lang="en"><head><meta charset="utf-8">
<meta name="viewport" content="width=device-width, initial-scale=1">
<title>Selfie booth</title>
<style>__STYLE__</style></head><body><main>
<h1>Selfie booth</h1>
<p id="checking">Opening the booth...</p>
<div id="steps" hidden>
  <h2>First time on this iPad</h2>
  <p>Do this once and the booth opens with no warning, on any Wi-Fi.</p>
  <ol>
    <li><a class="btn ghost" href="/booth-ca.crt">Download the booth certificate</a><br>Tap Allow.</li>
    <li>Open Settings, tap <b>Profile Downloaded</b> near the top, then Install.</li>
    <li>In Settings, go to General, About, Certificate Trust Settings, and turn on <b>Selfie Booth</b>.</li>
    <li>Come back here and tap Open the booth. Then Share, Add to Home Screen, for one-tap opening.</li>
  </ol>
  <a class="btn" href="__BOOTH__">Open the booth</a>
</div>
<script>
  // If this iPad already trusts the booth's certificate, the https check works: go straight in.
  const booth = "__BOOTH__"
  const done = new AbortController()
  setTimeout(() => done.abort(), 2500)
  fetch(booth + "status", { cache: "no-store", signal: done.signal })
    .then((r) => { if (!r.ok) throw r; location.replace(booth) })
    .catch(() => { document.getElementById("checking").hidden = true; document.getElementById("steps").hidden = false })
</script>
</main></body></html>"""

# Opens on the Mac when the booth starts: a QR code for the iPad, and whether the printer is there.
HOST_PAGE = """<!doctype html>
<html lang="en"><head><meta charset="utf-8">
<meta name="viewport" content="width=device-width, initial-scale=1">
<title>Selfie booth is running</title>
<style>__STYLE__
  main { text-align: center; }
  .qr { width: min(70vh, 420px); background: #fff; padding: 18px; border: 3px solid #3a2a47;
        border-radius: 22px; box-shadow: 6px 6px 0 #3a2a47; }
  .qr svg { display: block; width: 100%; height: auto; }
  .status { font-size: 26px; font-weight: 700; margin: 28px 0 8px; }
  .bad { color: #d6447e; }
</style></head><body><main>
<h1>Selfie booth is running</h1>
<p>Point the iPad camera at this code and tap the link.</p>
<div class="qr" style="margin: 0 auto">__QR__</div>
<p><code>__SETUP__</code></p>
<p class="status" id="printer">Checking the printer...</p>
<p>Keep the Start Booth window open while the booth runs.</p>
<script>
  async function check() {
    const el = document.getElementById("printer")
    try {
      const { printer } = await (await fetch("/status", { cache: "no-store" })).json()
      el.textContent = printer ? "Printer connected" : "Printer not found: plug it in and switch it on"
      el.className = printer ? "status" : "status bad"
    } catch { el.textContent = "The booth has stopped. Double-click Start Booth again."; el.className = "status bad" }
  }
  check(); setInterval(check, 3000)
</script>
</main></body></html>"""


def qr_svg(text):
    import qrcode
    import qrcode.image.svg

    out = io.BytesIO()
    qrcode.make(text, image_factory=qrcode.image.svg.SvgPathImage, border=1).save(out)
    return out.getvalue().decode().split("?>", 1)[-1]  # drop the XML header so it inlines in HTML


class Setup(BaseHTTPRequestHandler):
    """Plain http: the iPad setup page, the Mac's QR page, and the authority certificate."""

    pages = {}

    def log_message(self, *args):
        pass

    def do_GET(self):
        path = self.path.split("?")[0]
        if path == "/booth-ca.crt":
            body, kind = CA_CERT.read_bytes(), "application/x-x509-ca-cert"
        elif path == "/status":
            body, kind = json.dumps({"printer": printer.connected()}).encode(), "application/json"
        else:
            body, kind = self.pages["host" if path == "/host" else "setup"], "text/html; charset=utf-8"
        self.send_response(200)
        self.send_header("Content-Type", kind)
        self.send_header("Content-Length", str(len(body)))
        self.send_header("Cache-Control", "no-store")
        self.end_headers()
        self.wfile.write(body)

    do_HEAD = do_GET


def main():
    ip, own = lan_ip(), local_name()
    announcer = announce(ip)
    name = BOOTH_NAME if announcer else own
    cert, key = certificate([BOOTH_NAME, own], ip)
    ctx = ssl.SSLContext(ssl.PROTOCOL_TLS_SERVER)
    ctx.load_cert_chain(cert, key)

    https = ThreadingHTTPServer(("0.0.0.0", HTTPS_PORT), Booth)
    https.socket = ctx.wrap_socket(https.socket, server_side=True)
    booth_url, setup_url = f"https://{name}:{HTTPS_PORT}/", f"http://{name}:{HTTP_PORT}/"
    fill = lambda page: page.replace("__STYLE__", PAGE_STYLE).replace("__BOOTH__", booth_url)
    Setup.pages = {
        "setup": fill(SETUP_PAGE).encode(),
        "host": fill(HOST_PAGE).replace("__QR__", qr_svg(setup_url)).replace("__SETUP__", setup_url).encode(),
    }
    http = ThreadingHTTPServer(("0.0.0.0", HTTP_PORT), Setup)
    threading.Thread(target=http.serve_forever, daemon=True).start()
    if "--open" in sys.argv and sys.platform == "darwin":
        subprocess.run(["open", f"http://localhost:{HTTP_PORT}/host"])  # the QR page, on the Mac's screen

    print(f"Selfie booth ready at https://{name}:{HTTPS_PORT}")
    print(f"First time on an iPad? Open http://{name}:{HTTP_PORT} for the one-time setup.")
    print(f"(If that name doesn't work, use https://{own}:{HTTPS_PORT} or the IP, {ip})")
    print("Printer:", "connected" if printer.connected() else "NOT FOUND (plug it in and switch it on)")
    try:
        https.serve_forever()
    finally:
        if announcer:
            announcer.terminate()


if __name__ == "__main__":
    main()

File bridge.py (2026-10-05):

"""Act like a network printer: take whatever arrives on port 9100 and push it to the Rollo.

Not used by the booth page (that goes through server.py); handy for sending
raw TSPL files from anywhere: nc <host> 9100 < label.tspl
"""

import socket

from printer import Printer

printer = Printer()
s = socket.socket()
s.setsockopt(socket.SOL_SOCKET, socket.SO_REUSEADDR, 1)
s.bind(("0.0.0.0", 9100))
s.listen(1)
print("listening on 9100")
while True:
    conn, addr = s.accept()
    data = b""
    while chunk := conn.recv(65536):
        data += chunk
    conn.close()
    print(f"{addr[0]}: {len(data)} bytes")
    printer.send(data)

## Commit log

2026-10-05 Thermal selfie booth: iPad page prints to a USB Rollo via a small server
2026-10-05 Add Hearts, Bubble, Ticket, Checker and Stamp frames, plus a frames preview page
2026-10-05 Multi-pose layouts and sticker packs
    Layouts: 2 poses, 3 strip, 2x2, twin strips (cut in half), plus the single
    photo frames. Sticker packs (sparkles, hearts, flowers, bows, smileys, party,
    lightning) work on any layout. The booth counts down once per pose.
2026-10-05 Pick a layout first, with live tiles; add Heart border layout
    The booth opens on a grid of layouts, each showing the camera in that layout.
    Tapping one goes to the camera; after a print, or a minute idle, it returns.
    Caption, date and sound move to a host row under the tiles.
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2026-10-05 Each pattern comes with its own stickers; drop the sticker step
    Hearts, Polka dot, Gingham and Daisy chain lead the pattern list.
2026-10-05 Simplify: 4 photo counts, 5 patterns, select then Next
    Photos: 1, 2 poses, 2x2, twin strips. Patterns: plain, hearts (hearts),
    polka dot (bows), gingham, daisy chain (flowers). Tapping a tile selects it
    and Next moves on; caption/date/sound sit behind a Settings button.
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2026-10-05 Camera fills one slot at a time, with a pause between poses
2026-10-05 Caption is its own step, with a live label preview
    Flow is now: photos, pattern, caption (with the date toggle), take photos.
    Captions start blank for each guest. The label preview sizes to the space left.
2026-10-05 Captions setting: guests write their own, or one for everyone
    In event mode the caption is set once in Settings and the caption step is
    skipped, so the flow is photos, pattern, smile.
2026-10-05 Twin strips: white gutter with a bold dashed cut line and scissors
2026-10-05 Hearts outline each photo with small hearts; Daisy chain uses real daisies
    The border daisies have outlined white petals, so they read differently from
    the solid flower stickers.
2026-10-05 Lighter gingham: light grey stripes, mid grey crossings
    Halftone dots stay at real pixel size on scaled previews so they match the print.
2026-10-05 Doodle on the Plain pattern in step 3
    Guests draw on the label preview with a finger (Undo, Clear). Strokes print on
    top of everything with a white edge. With one caption for everyone, step 3
    still appears on Plain as "Doodle on it".
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2026-10-05 No more certificate warning, and one address on any network
    The server makes its own certificate authority; each iPad trusts it once from
    a setup page on http :8000. It announces selfie-booth.local over Bonjour, and
    re-issues the server certificate when the IP changes, so the address and the
    trust survive network changes.
    [server.py]
2026-10-05 Double-click Start Booth for non-technical setup; no Homebrew needed
    libusb-package bundles libusb, the start file sets up Python on first run,
    keeps the Mac awake, and explains what to do if Apple's developer tools are missing.
    [printer.py]
2026-10-05 QR code page on the Mac; trusted iPads skip setup and go straight in
    Start Booth opens a page with a QR code and live printer status. Scanning it
    lands on the setup page, which probes the booth over https and jumps straight
    in when the iPad already trusts it.
    [server.py]
2026-10-05 Add the booth stand: printed saddle and cradle, laser-cut bezel and front plate
    The saddle straddles the Rollo X1038 and carries a cradle holding the iPad mini
    tilted back 15 degrees. A scalloped bezel with a selfie booth sign hangs on the
    cradle, and a front plate with a label slot hangs on the legs.
    [bezel.dxf, booth.step, cradle.step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]
2026-10-05 Stand uses about half the filament: thinner walls, heart cutouts, deck windows
    [bezel.dxf, booth.step, cradle.step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]
2026-10-05 3D-printable versions of the bezel and front plate
    Raised lettering for a colour change, and a shorter sign so the bezel fits a
    256 mm plate.
    [bezel.dxf, bezel_print.3mf, front_plate_print.3mf]
2026-10-05 Use less material: shorter cradle, bigger cutouts, 2 mm printed panels
    About 28% less across all four printed parts, fit unchanged.
    [bezel.dxf, bezel_print.3mf, booth.step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]
2026-10-05 Add a sign topper above the iPad and a standing table sign
    The topper's posts slide into new sleeves on the back of the cradle; its text is
    one constant (SIGN_TEXT). The full booth assembly now includes every part.
    [cradle.step, cradle_print.3mf, sign_topper_print.3mf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]
2026-10-05 Lighter table sign and base
    [table_sign_base_print.3mf, table_sign_print.3mf]
2026-10-05 Make the stand fit together properly, with a check for every joint
    The cradle's ribs now run up solid back plate (the heart window is smaller and
    sits between them), every peg grows from a solid pad instead of a 5 mm edge,
    the cradle sits on solid deck, and checks/fit_check.py verifies parts are one
    piece, nothing collides, and pegs, keyholes, screws and sleeves line up.
    [bezel.dxf, bezel_print.3mf, cradle.step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]
2026-10-05 Paper setting: 4x6 labels or roll, 4x4, 4x3, 4x2, 3x2
    Designs reflow to the paper's width and length, previews take its shape, and the
    printer gets the matching size and gap. Small papers only offer the photo counts
    that fit, and skip step 1 when that's just one.
    [printer.py, server.py]
2026-10-05 Laser-cut convention box: everything inside, iPad captured, back on thumb screws
    393 x 270 x 265 mm finger-jointed box in 6 mm plywood, every piece cuttable on a
    Glowforge. iPad behind a front window (narrower than the iPad), Rollo on a shelf
    behind the print slot, labels behind it, 2024 Mac mini underneath with vents.
    checks/box_check.py verifies parts, collisions, slot and camera alignment, and bed fit.
    [back.dxf, bottom.dxf, box.step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]
2026-10-05 Box: show the whole iPad in a raised frame, clean top, no feet, slot follows the label exit height
    The window is the iPad face minus a 2.5 mm lip (camera inside it), with a raised
    frame round it. No top sign or top slots; the divider glues under the top. No
    feet: Mac mini air comes through heart vents in the side. The print slot is
    centred on LABEL_EXIT_Z, to be measured on the real printer.
    [bottom.dxf, box.step, divider.dxf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]
2026-10-05 Box holds a 14 in MacBook Pro in a bay under a full-width deck
    Replaces the Mac mini and printer shelf: the MacBook lies closed in the bottom
    bay and slides out the back; the iPad, printer and labels stand on the deck,
    with cable holes down. Low heart vents on both sides and the back. README covers
    clamshell mode (HDMI dummy plug + charger).
    [back.dxf, bottom.dxf, box.step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]
2026-10-05 Box: tall print slot that catches the label wherever it leaves the printer
    130 x 60 mm, covering the upper printer front from 35 mm up to 5 mm above the
    top, so the exit height doesn't need measuring. Check confirms coverage and that
    the bezel clears the round sign.
    [box.step, front.dxf, slot_bezel.dxf]
2026-10-05 Box: nine plywood pieces, no screws or hardware
    The iPad stands on the deck, held against the window by one tabbed plate (its
    cable plugs down through the deck). The back drops into floor slots and is held
    by a lock bar sliding through both side walls. Decoration is engraved instead of
    glued on. Divider, pocket, posts and all screws are gone.
    [back.dxf, bottom.dxf, box.step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]
2026-10-05 Code to start: a keypad before each paid session, 0000 by default
    Each correct code unlocks one session (pick, pose, print), then the booth locks
    again; idle sessions lock after a minute. Settings needs the code too, and can
    turn the lock off or change the code.
2026-10-05 Box cut and assembly guide (PDF, with the renders and HTML it's built from)
2026-10-05 Ready-to-cut sheets: the box on seven 12 x 20 in sheets, as Glowforge SVG and DXF
    [sheet1_front.dxf, sheet2_back.dxf, sheet3_top.dxf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]
2026-10-05 Drop the decorative hearts from the box; add SendCutSend files
    The holder, back and side-wall hearts are gone; the back keeps one row of plain
    vent slots behind the MacBook. Through-slots get 0.25 mm clearance all round, and
    src/box_sendcutsend.py writes per-piece DXFs for their 6.35 mm birch, cut layer only.
    [back.dxf, bottom.dxf, box.step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]
2026-10-06 Live box generator on the website, 1/4 in MDF by default
    docs/box.html redraws the cut sheets for any wood thickness in the browser, downloads
    them as a ZIP (Glowforge SVGs + DXFs) and shows the box in 3D. docs/box/box.js ports
    src/box.py; checks/box_web_check.mjs matches it to the Python model at 5.5, 6.35 and 7 mm.
    The Glowforge SVG engraving now fills evenodd, so the band round the iPad window no
    longer engraves the whole window.
    [back.dxf, bottom.dxf, box.step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]
2026-10-06 Drop all engraving from the box: cut lines only
    [front.dxf, sheet1_front.dxf]
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
